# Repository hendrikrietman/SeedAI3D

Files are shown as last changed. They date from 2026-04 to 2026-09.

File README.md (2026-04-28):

# SeedAI3D

> AI-augmented, 3D-printable, breeder-first vacuum precision sowing element.

## What is this

A precision sowing element designed for plant breeders, not for industrial agriculture. Open-source, parametric, 3D-printable.

Commercial precision seeders (Monosem, MaterMacc, Stanhay) cost €5,000-25,000 and are built for thousand-hectare farming. They don't serve the plant breeding community well: small plots, frequent line changes, zero contamination tolerance, need for line-tracking.

SeedAI3D fills that gap. Estimated cost per element: €50-150 (printed parts + electronics + small parts).

## Distinguishing features

- **Vacuum pickup from seed-pool** — Earthway/MaterMacc-style
- **Zero-loss recovery bowl** surrounding disc seed-path — fallen seeds return to pool
- **Dual-tube self-cleaning** between lines (feeder + vacuum-cleaner-port)
- **Parametric design** adaptable to soybean, edamame, lima, snapbean
- **Optional RTK GPS integration** for plot-tracking and adaptive sowing speed

## Status

Prototype design phase. CAD architecture complete. First 3D-print pending.

This repository contains:
- Parametric OpenSCAD designs
- Three.js interactive viewer (real-time animated cycle visualization)
- Build documentation
- Design rationale and architecture decisions

## Architecture phases

- **Phase 1:** 132mm tilted disc with 60 teeth, 40 pickup-holes (Ø4mm)
- **Phase 2:** Bottom seed-pool architecture
- **Phase 3:** Singulator deflectors + guide funnel + 6-state seed lifecycle
- **Phase 4:** Vacuum chamber with O-ring sealing
- **Phase 6:** Integrated mal-plate (motor + drive + chamber in one)
- **Phase 7:** Transparent housing with integrated tubes (in progress)

## License

CC-BY-SA 4.0 — share-alike, attribution required.

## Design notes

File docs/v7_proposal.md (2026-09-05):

# SeedAI3D v7 — design proposal (unbuilt)

**Status:** proposal, September 2026. No parts printed. No SCAD yet; the geometry lives in the
parameter block of `viewer/v7/index.html` and is meant to be ported to `scad/` once the first
print of v5.8/v6.0 has answered the questions in §8.

Supersedes the v5.8.5 geometry in this repo. Carries over from v6.0 (June 2026, not pushed):
crop-swappable discs, the blow-off sector, the Ø20 vacuum nipple, 3 mm chamber back wall.

Interactive model: `viewer/v7/index.html` (seed physics, cut-away, explode, count mode).

## 1. Why revisit

v5.8 had 12 printed parts plus a lid ring, dust ring, O-ring cord, heat-set inserts and clip
posts. Most of them exist to fix problems the model itself introduced:

| v5.8 part | Why it existed | Why it goes |
|---|---|---|
| Geleider (catch chute), afstrijker 2, vertical drop tube | The viewer's free-fall model showed the seed missing the centre hole at θ=90° | On a 45° face, downhill at the top of the disc *is* radially inward. After vacuum cuts, a soybean rolls the 20 mm from the hole circle to the centre hole in ~0.1 s (a ≈ 4.5 m/s²). Tangential drift at 15 rpm is 4 mm. D9's "glide" already noticed this. |
| Lid ring, dust ring, 4 clip posts, M3 inserts | Cover the external teeth | Teeth move to an internal ring gear on the disc back; nothing on the front needs covering |
| Hopper, feeder tube, vac-cleanup tube | Seed supply and line change | Seeds rest on the 45° face; the pool is a collar around the bottom of the drum. Cleanout is by geometry (§4) or by the wall gate (field), not by a shop-vac 2000 times |
| NBR O-ring cord in a groove | Chamber seal | Static-seal geometry on a rotating face: line contact, high drag, wears the PETG disc. Replaced by a flat printed TPU gasket frame, as Monosem/MaterMacc do |

What was missing: a defined disc axis (v5 floats in a Ø134 recess), a seed sensor, a
singulator that can actually strip a double, chamfered holes, mounting bosses, a cover, and a
geometry that lets the *last* seed reach a hole.

## 2. Parts (nine)

1. **Disc** — Ø128 × 4, 32 holes Ø4 at R45 (pitch 8.8 mm; the v5 40 at R42 gave 6.6 mm, so
   adjacent soybeans touched), Ø50 centre hole, rim flange Ø133 × 2 on the front, internal ring
   gear (75 T, m1.5) on the back, 11.5 mm tall. Crop discs: swap hole count/diameter only.
2. **Plate** — Ø150 × 21. Back slab, ring-gear groove, full-360° seal land with the vacuum
   chamber (R41–49, θ 90–270) and blow-off pocket (θ 68–84) cut into it, outer wall, motor
   shaft bore, vacuum and blow-off nipples, dust drain slot under the ring cavity, two
   mounting bosses.
3. **Gasket** — TPU, two frames 2.5 mm wide, 1.5 mm thick, around chamber and blow-off.
4. **Funnel** — one lathe part: Ø54 front flange (retains the disc), Ø49.4 skirt (centre
   journal in the disc hole), cone Ø46→Ø24, bayonet flange behind the plate, exit tube.
5. **Pinion** — 25 T m1.5 on the NEMA17 shaft, sitting *behind* the seal land (z −16.5…−10.5)
   so no pickup hole ever passes over an open gear pocket.
6. **Collar** — static ring; flat underside 0.3 mm above the disc face (seals rim and
   flange), top face from R49 at the disc to R55 at the cover. See §4.
7. **Singulator finger** — hangs from the collar at θ≈232°, adjustable height.
8. **Cover** — clear PETG plate Ø144 × 3, three thumb screws.
9. **NEMA17 + TMC2208/2209** (bought).

Wall gate: the bottom 50° of the collar, hinged at its outer edge. Field mode only.

## 3. Z-stack (disc-local, front = +Z, mm)

| z | what |
|---|---|
| 20 … 23 | cover |
| −3 … 20 | collar rim / drum wall |
| −2.5 … −0.5 | disc rim flange (over the wall top: labyrinth) |
| −4.5 … −0.5 | disc body |
| −6 … −4.5 | TPU gasket |
| −10 … −6 | seal land, full 360°, R38–53 |
| −16 … −4.5 | ring gear on the disc back, R54.75 (tips) – 63 |
| −16.5 … −10.5 | pinion, centre (37.5, 0) |
| −21 … −16 | back slab |
| < −21 | motor, nipples, bosses |

Assembly: disc drops in from the front; funnel goes through the centre hole and locks with a
quarter turn behind the plate; cover on. Crop change is tool-free.

## 4. The last seed (collar geometry)

On a 45° disc the lowest point in the drum is the corner between the disc face and the wall.
With holes at R45 and a wall at R65 that corner is 14 mm (world) below the lowest hole. Every
seed ends there and no hole ever passes: v5–v7a could not empty by design.

Fix: make the hole circle the lowest point. The collar's top face runs from the hole circle
(R49, 0.3 mm above the face) to the cover (R55, z 20) at 73° to the disc face, i.e. 28° below
horizontal in the world. A surface must be steeper than 45° + friction angle relative to the
disc face for seeds to slide *inward*; 73° gives ~25° margin for soybean on PETG. Every point
in the drum then has a downhill path into the V between disc face and collar, whose bottom line
is the hole circle. Held seeds (R42–48) clear the collar edge by 1 mm.

Pool capacity in the V is small (tens of seeds); bulk lives in the hopper (§5).

## 5. Hopper

Vertical axis, 70° walls, transparent, one orifice, no ledges. A Ø25 tube (bore ≥ 3× seed
diameter; the v5 Ø14 would bridge with edamame) at ≥45° discharges onto the disc face *inside*
the hole circle at θ≈305°, so everything it delivers also drains into the V. Flow is
self-regulating: when the V is full the pile backs up to the orifice.

## 6. Modes and firmware

Same board and code for bench and planter. Board: Arduino Mega 2560 + RAMPS 1.4 (5 driver
sockets, 6 endstop inputs for IR gates, servo headers for gates, MOSFET outputs for blowers,
12864 LCD with encoder, buzzer and SD). 32-bit BTT SKR or ESP32/Arduino framework are
equivalent routes. Step rate at 20 rpm disc: 200 full steps/s per motor; 1/4 µstep, four
motors = 3200 steps/s, within a Mega + AccelStepper.

- **COUNT** (bench): target N from the encoder; full speed until N − (in-flight + 2), where
  in-flight = rpm·32/60·0.35 s is the number of seeds already released but not yet at the
  gate; then 2 rpm (one seed per second); stop on the Nth gate pulse; vacuum off so held seeds
  slide back. No bag on the holder → no count.
- **EMPTY** (last bag): 30 rpm, vacuum on, stop when the gate has been silent for 2.5 s
  (40 empty hole passes). Display the line total.
- **SOW** (planter): row list (line, N) from SD; live count vs N; row-done; gate cycle on
  the button: vacuum off → held seeds slide back → gate open ~1.5 s → close.
- IR gate in the funnel tube on an interrupt; occlusion time distinguishes a double.
- The SD CSV is the whole data path from winter counting to spring sowing: the bag counted on
  this disc is the row this disc meters.

## 7. Blower

40–70 mbar at the chamber for soybean-size seed: a small 12/24 V centrifugal blower per element
on a MOSFET output, not a shop vac.

## 8. Open questions — what the first print has to answer

1. Does the V actually feed the last seed? Collar edge radius and angle are the numbers to
   vary.
2. Gap-seal leakage with the TPU gasket vs. none.
3. Does a 75 T internal ring print true enough in PETG to mesh without backlash noise?
4. Doubles rate at the gate with the singulator at 2.4 mm above seed height.
5. Rim labyrinth: does anything reach the ring cavity, and does the drain clear it?
6. Not modelled: curved seed tube from the 45° exit to the furrow; row-unit bracket.

Counting accuracy is a hypothesis until a real disc has run a few thousand soybeans past a
real gate.

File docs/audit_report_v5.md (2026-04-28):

# V5 Audit Report — 2026-04-28 (post-Phase-5)

> Read-only inventory of `~/workspace/protisem-v4/`. No code or geometry was
> changed during this audit; only this report file was rewritten.
>
> This is the **second** audit of the V5 tree. The first (earlier today)
> drove the v5.6.0 Phase-5 commit and is preserved in this file's git
> history if needed for comparison. Everything below reflects the state at
> commit `5bafb4c` / tag `v5.6.0` / tag `phase5-backup`.

## Summary

The repository is in a **clean post-Phase-5 state**: 16 commits, working
tree clean, two new tags (`v5.6.0`, `phase5-backup`). Phases 1–5 are
implemented in code with matching SCAD + STL pairs; the entire validation
suite (36/36 checks) passes. **Phase 6 (gear drive + motor mount) has not
been started** — no parameters, no SCAD source, no STL, no viewer wiring.
That is expected; Hendrik asked for the backup tag *before* Phase 6.

The drift items the previous audit flagged have all been closed:
- Viewer `POOL` block now uses half-disc geometry (R_OUTER=55, depth 33,
  floor −50) consistent with `parameters.scad`.
- Stale `stl/v4_2/{disc,reservoir}.stl` removed from the tree.
- `decisions.md` gained D8 (V5 FLIP), D9 (vacuum-respecting glide),
  D10 (half-disc pool footprint).

The only remaining caveat: Phase-5 changes have **not been visually
verified in a browser** in this build environment (no display).

## File inventory

```
~/workspace/protisem-v4/

scad/
  lib/helpers.scad                  1.2 KB    2026-04-27 16:01
  lib/parameters.scad              15.0 KB    2026-04-28 15:43   ← Phase 5 added
  v4_1_disc.scad                    2.6 KB    2026-04-27 16:01
  v5_2_seed_pool.scad               8.8 KB    2026-04-27 21:31
  v5_3_barriere_geleider.scad       9.9 KB    2026-04-27 19:37
  v5_4_vacuum_chamber.scad          7.4 KB    2026-04-27 19:34
  v5_5_recovery_bowl.scad           6.9 KB    2026-04-28 15:44   ← NEW

stl/
  v4_1/disc.stl                     2.3 MB    2026-04-27 18:54
  v5_2/disc.stl                     2.3 MB    2026-04-27 18:55
  v5_2/seed_pool.stl              430.4 KB    2026-04-27 21:31
  v5_3/afstrijker.stl               2.4 KB    2026-04-27 19:38
  v5_3/afstrijker2.stl              2.3 KB    2026-04-27 19:38
  v5_3/geleider.stl                80.7 KB    2026-04-27 18:03
  v5_3/drop_tube.stl               82.4 KB    2026-04-27 18:01
  v5_4/vacuum_chamber.stl         150.0 KB    2026-04-27 19:35
  v5_5/recovery_bowl.stl           98.1 KB    2026-04-28 15:44   ← NEW
  (stl/v4_2/ deleted in v5.6.0)

viewer/
  index.html                        4.5 KB    2026-04-28 15:49
  viewer.js                        38.4 KB    2026-04-28 15:51   ← +clean cycle, POOL fix
  styles.css                        1.8 KB    2026-04-28 15:49   ← +.btn class
  package.json + package-lock.json + node_modules/three (vendored)
  vendor/three.module.js + vendor/addons/ (importmap targets)
  models/
    disc.stl                        2.3 MB    2026-04-27 18:59
    seed_pool.stl                 430.4 KB    2026-04-27 21:33
    afstrijker.stl + afstrijker2.stl
    geleider.stl
    drop_tube.stl
    vacuum_chamber.stl
    recovery_bowl.stl              98.1 KB    2026-04-28 15:47   ← NEW

validation/
  geometry_check.py                23.8 KB    2026-04-28 15:52   ← +check_recovery_bowl

docs/
  build_log.md                     38.4 KB    2026-04-28 15:54   ← +V5.6.0 entry
  decisions.md                     16.0 KB    2026-04-28 15:53   ← +D8/D9/D10
  audit_report_v5.md               17.6 KB    2026-04-28 15:35   ← rewritten by this audit

renders/
  v4_1/  4 PNG (Phase-1 disc)
  v4_2/  4 PNG (V4 era — still on disk; the SCAD source was retired)
  v5_2/  3 PNG (assembly + v5.5.1 + v5.5.2 iso)
  v5_4_anchor/  3 PNG (chamber anchor verification)
  v5_5/  v5_5_iso.png  183.7 KB  2026-04-28 15:47   ← NEW

scripts/
  render_all.sh                     1.6 KB
  update_viewer.sh                  0.5 KB
```

## Phase status

### Phase 1 — Disc
- SCAD: **present** (`scad/v4_1_disc.scad`)
- STL: **present** (`stl/v4_1/disc.stl`, copied to `viewer/models/`)
- `PICKUP_HOLE_DIA = 4.0 mm`  ✓ (per Phase-4 spec; soybean Ø~6 mm cannot pass)
- `PICKUP_HOLE_COUNT = 40`    ✓
- `DISC_TILT_DEG = 45°`       ✓
- Status: **complete, unchanged since first audit**

### Phase 2 — Reservoir / pool
- V4 top-funnel reservoir: **retired** (no SCAD source, no orphan STLs anymore)
- V5 bottom seed-pool: **active**, `scad/v5_2_seed_pool.scad`
  - Half-disc body, R_OUTER=55, footprint y ≤ 0
  - V-cone bottom 4×4 mm at (0, −30, floor+2), floor z=−50
  - Front-mount feeder tube (OD 18, ID 14, 60° elev) included
  - Top-mount vac-cleanup tube (OD 26, ID 22, 80° elev) included
- Status: **complete, unchanged since first audit**

### Phase 3 — Afstrijkers + geleider + animation
- Afstrijker 1 at θ=250° (singulator, height 8): **present** ✓
- Afstrijker 2 at θ=95° (release pusher, height 6): **present** ✓
- Geleider catch-mouth 40×20 at z=20, y_centre=30: **present** ✓
- Drop-tube OD 30 / ID 24, z_top=−6, z_bottom=−52: **present** ✓
- 6-state seed-lifecycle animation (pool → attached → falling → gliding →
  exiting → landed) with HUD counters: **implemented** ✓
- Status: **complete, unchanged since first audit**

### Phase 4 — Vacuum chamber
- Annular sector (R_in=30, R_out=50, depth 8, sector θ ∈ [90°, 270°]
  through 180°, world x ≤ 0): **present** ✓
- Ø 12 hose nipple, length 30 mm: **present** ✓
- Air gap 1.5 mm between disc and back-wall: implemented as
  `EPS = 0.01` slight inset at the disc-side opening (chamber's "front"
  is the disc back face); the seal is implicit at R=30 and R=50.
- **Boog-vormige rubber seal**: **not a separate modeled part**. The
  spec calls for a curved O-ring at R=30 and R=50; current SCAD leaves
  this as an implicit interface to be added in BOM/printing. Flagged
  but acceptable for digital geometry.
- Status: **structurally complete; seal element implicit (BOM concern)**

### Phase 5 — Recovery bowl + dual tubes + clean cycle
- Half-circle bowl around disc TOP half: **present** ✓ (NEW in v5.6.0,
  `scad/v5_5_recovery_bowl.scad`, `stl/v5_5/recovery_bowl.stl`).
  Half-disc shell, footprint y ≥ 0, R_OUTER=55, z ∈ [22, 50]. Floor
  flush on the geleider top with a 40×20 drain at y=30 aligned to the
  geleider catch-mouth. Disc-envelope subtraction (3 mm clearance)
  carves the slot where the rim crosses the outer wall.
- Feeder tube 60° from front: **present** ✓
- Vac-cleanup tube 80° from top: **present** ✓
- Self-cleaning animation button: **present** ✓ (NEW in v5.6.0).
  "Start clean cycle" button in the controls panel toggles
  `cleanCycleActive`. While active: vacuum forced to 0 internally,
  pool refill suppressed, pool seeds animated through the vac-cleanup
  tube at 3/s into a new "Cleaned" HUD counter.
- Status: **complete in code, awaiting browser eyeball verification**

### Phase 6 — Aandrijving + motor (gear drive + motor mount)
- BLDC motor mount: **MISSING**
- Drive pinion (20 teeth): **MISSING**
- Engagement with disc tooth-rim (60 teeth): **MISSING**
- Motor angle (45°): **N/A** (motor not yet placed)
- Motor rotation animation synchronous with disc: **N/A** (motor not yet present)
- No `parameters.scad` entries for `MOTOR_*` / `PINION_*`
- No `scad/v5_6_*.scad` source file
- No `stl/v5_6/` directory
- No viewer mesh load or toggle for motor / pinion
- Status: **not started — expected; Hendrik tagged `phase5-backup` first**

## Viewer state

`index.html` and `viewer.js` are loaded together via an importmap pointing
at `./vendor/three.module.js` and `./vendor/addons/`. Title now reads
"PROTISEM V5 — Phase 5 (recovery bowl + clean cycle)".

### STL meshes loaded (cache-busted with `?v=${Date.now()}`)
- `disc.stl`            — PETG-blue, rotates around `DISC_AXIS`
- `seed_pool.stl`       — translucent grey
- `afstrijker.stl` + `afstrijker2.stl` — dark grey
- `geleider.stl`        — translucent dark
- `drop_tube.stl`       — translucent dark
- `vacuum_chamber.stl`  — translucent dark blue
- `recovery_bowl.stl`   — translucent yellow-amber (NEW)

Procedural groups: pool-fill seeds (target 50, refill at <12), attached
seeds, falling/gliding/exiting/cleaning seeds (5 distinct materials),
pickup/release marker spheres, 40 per-hole vacuum-glow markers.

### UI toggles (controls panel, top-left)
1. RPM slider 0–30 (default 5.0)
2. Vacuum slider 0–100 (default 80)
3. Cross-section (cut +X half)
4. Pickup / release markers
5. Seed-pool fill
6. Seeds on disc (red)
7. Afstrijker 1 (pickup singulator)
8. Afstrijker 2 (release pusher)
9. Geleider (catch chute)
10. Drop-tube
11. Vacuum-kamer (transparant)
12. Vacuum-glow (active hole markers)
13. **Recovery bowl (top-half catch)** — NEW in v5.6.0
14. **"Start clean cycle" button** — NEW in v5.6.0

### State counters (info panel, top-right)
- Rotation angle
- Pool seeds
- On disc
- In geleider
- In drop-tube
- Sown (cum.)
- Skipped (cum.)
- Missed (cum.)
- **Cleaned (cum.)** — NEW in v5.6.0

### Animation
Implemented in `requestAnimationFrame` loop (`animate()`). Seed lifecycle:
pickup at θ=270° → travel on disc-front face → vacuum-respecting glide
to drop-tube at θ=90° → land. Singulator slip 5%, push-pusher 10%,
vacuum<5 → free-fall. Anchor verification logs PASS/FAIL on every STL
load. **fps not measurable in this audit environment** — the build
environment has no display; needs a browser run.

## Inconsistencies detected

### Carried-over from first audit — all resolved in v5.6.0

1. **Viewer `POOL` block stale**: closed. `viewer.js:97-105` now declares
   `{ rOuter: 55, wall: 2, depth: 33, zTop: -17, zFloor: -50, yCenter: -30,
   fillZ: -24 }`, matching `parameters.scad`. `placePoolSeed()` rewritten
   to spawn within the half-disc footprint with chord-bound x range.
2. **Stale V4 STLs**: closed. `stl/v4_2/{disc,reservoir}.stl` deleted via
   `git rm`; the (now-empty) directory is gone from the tree.
3. **`decisions.md` lag**: closed. D8 (FLIP), D9 (vacuum-respecting glide),
   D10 (half-disc pool) backfilled.

### Hardcoded values in viewer.js

The following geometric constants are hardcoded in `viewer.js`. All
values **match** `parameters.scad`. The viewer has no SCAD parser; this
is the intentional architecture (vendored constants kept in sync):
- `TILT = π/4`, `R_PICKUP = 42`, `N_HOLES = 40`, `SEED_RADIUS = 3`
- `PICKUP_THETA = 270°`, `RELEASE_THETA = 90°`
- `AFSTRIJKER_THETA = 250°`, `AFSTRIJKER2_THETA = 95°`
- `AFSTRIJKER_SLIP_PROB = 0.05`, `AFSTRIJKER2_PUSH_PROB = 0.10`
  (these are visualisation-only probabilities, not geometry; SCAD has
   matching values for documentation but nothing imports them)
- `GELEIDER`, `DROP_TUBE`, `POOL`, `BOWL` blocks ✓
- `DISC_THICKNESS = 4`, `AFS_HEIGHT = 8`, `AFS2_HEIGHT = 6` ✓
- `VAC_CLEAN_MOUTH = (0, -42, -43)`, `VAC_CLEAN_DIR` from 80° elev ✓
- `CLEAN_RATE = 3.0` (visualisation-only, no SCAD equivalent)

No drift detected.

### SCAD-vs-SCAD contradictions

None. Single canonical version of each component:
`v4_1_disc.scad` (Phase 1) → `v5_2_seed_pool.scad` (Phase 2 V5) →
`v5_3_barriere_geleider.scad` (Phase 3) → `v5_4_vacuum_chamber.scad`
(Phase 4) → `v5_5_recovery_bowl.scad` (Phase 5).
The retired V4 reservoir SCAD is not on disk (per D6).

### Phase 4 vacuum chamber

It works. Anchor verification (`viewer.js:472-484`) reports PASS for the
chamber STL centroid against the expected `(-26.67, +6.67, -6.67)`
post-FLIP position with `disc_plane_eq < 0` (back side). Earlier renders
are saved in `renders/v5_4_anchor/{front,iso,side_x}.png`.

### Seed position offset

The audit prompt says "5 mm offset langs FRONT_NORMAL". The code uses
`SEED_RADIUS = 3 mm` (`viewer.js:165`, `viewer.js:826`). Reasoning
(`viewer.js:124-126`): seed Ø=6 mm sits with its near pole tangent to
the disc-front face around the 4 mm hole, so seed-centre offset =
SEED_RADIUS = 3 mm. Geometrically correct; the prompt's "5 mm" appears
to be a misremember from an older revision. Same observation as the
first audit; **not changed**.

### Phase-5 specific notes

- Recovery bowl `disc_clearance` validation passes at min=2.92 mm vs
  nominal 3.00, with a 0.15 mm tolerance to absorb the OpenSCAD `$fn=64`
  chord error at R=66 (R·(1−cos(π/$fn)) ≈ 0.08 mm). Geometrically
  correct; the gap is faceting noise, not interference.
- Bowl floor at z=22 has an intentional slot in y∈[19.2, 24.8] where
  the disc body slab |z−y|≤2.83 passes through — same kind of slot the
  bottom pool has (D6) and the geleider has (D7). The slot leaks; real
  hardware will need rim-following sealing brushes, deferred.
- The bowl catches seeds in the y > 0 half-plane between roughly θ=90°
  and θ=120° release (where vacuum drop on the upper arc would deposit
  a seed). The y < 15 floor region is reachable but unlikely to receive
  seeds in normal operation.

### Air gap on vacuum chamber

The Phase-4 spec reads "1.5 mm air gap tussen disc en static back-wall".
The current SCAD uses `EPS = 0.01 mm` inset at the chamber-front /
disc-back interface. There is no explicit 1.5 mm gap modelled. Reading
of the original spec is ambiguous: the gap could be a mechanical
clearance for the rotating disc, or a design parameter for the seal.
Current model assumes the disc back face IS the chamber front cover
(zero gap, sealed by O-rings at R=30 and R=50). If Hendrik wants a
non-zero gap modelled, that would be a separate clarification before
Phase 6.

## Build log status

`docs/build_log.md` (655 → 715 lines) now covers:
- Phase 1 — Parametric disc + viewer bootstrap
- Phase 2 — Reservoir + viewer integration (V4 funnel, retired)
- Phase 2 fix — pickup/release θ correction
- Phase 2 V5 — architecture switch to vacuum bottom-pool (D6)
- Phase 3 V5 — afstrijker + geleider + lifecycle animation
- Phase 3 V5 visual fixes — seed offset, raised pool, release pusher
- Phase 3 V5 fix — `FRONT_NORMAL` derived from pool reference
- Phase 4 V5 — vacuum chamber + 4 mm holes + corrected seed mechanics
- V5 anchor-based verification
- V5 FLIP — seeds and chamber side-swap
- V5 polish — vacuum-respecting glide + front-face tube ports
- V5.5.0 — wider feeder + vac tube relocated to top
- V5.5.1 — V-cone in both X & Y, floor lowered
- V5.5.2 — half-disc footprint pool, wraps disc bottom 180°
- **V5.6.0 — Phase 5: top-half recovery bowl + clean-cycle animation** (NEW)

`docs/decisions.md` (132 → 248 lines) now contains 10 numbered decisions:
D1 (tilt axis), D2 (Phase-1 open items), D3 (three.js vendoring),
D4 (reservoir outlet — historical), D5 (θ=110/70 — superseded),
D6 (V5 architecture), D7 (geleider throat below disc-body slab),
**D8 (V5 FLIP)**, **D9 (vacuum-respecting glide)**, **D10 (half-disc pool)**.

What's not yet documented:
- Phase 6 architectural decisions (motor placement, gear ratio, mount
  attachment to housing). Will be written when Phase 6 starts.

## Git status

- Branch: `master`, working tree clean
- 16 commits since `Phase 0: scaffolding`
- Latest commit: `5bafb4c v5.6.0: Phase 5 — top-half recovery bowl +
  clean-cycle animation` (2026-04-28 15:56 UTC, today)
- Tags: `v4.1`, `v5.2`, `v5.3`, `v5.3.1`, `v5.4`, `v5.4.2`, `v5.4.3`,
  `v5.5.0`, `v5.5.1`, `v5.5.2`, **`v5.6.0`**, **`phase5-backup`** (last two NEW)
- `phase5-backup` is the explicit rollback point Hendrik requested before
  Phase 6 begins. `git reset --hard phase5-backup` restores the tree.

## What's complete

- Phases 1–5 all have SCAD source + STL output + viewer integration.
- All 36 validation checks PASS:
  - Phase 1 disc: 5 checks
  - Phase 2 V5 pool + clearance: 8 checks
  - Phase 3 afstrijkers + geleider + drop-tube: 12 checks
  - Phase 4 chamber: 4 checks
  - Phase 5 recovery bowl: 7 checks
- 6-state seed lifecycle animation runs with HUD counters
  (pool / on-disc / in-geleider / in-drop-tube / sown / skipped / missed
  / cleaned).
- Self-cleaning UI cycle implemented in viewer (button + state machine).
- Anchor-based verification gates every STL load with PASS/FAIL log.
- Backup tag `phase5-backup` exists; clean working tree.

## What's incomplete or broken

- **Phase 6 not started**: motor mount, drive pinion (20T), gear engagement
  geometry, motor rotation animation. None of: SCAD source, STL,
  parameters, viewer wiring. Expected per Hendrik's instruction.
- **Phase 5 browser eyeball not done**: recovery bowl visual, clean-cycle
  animation, and updated pool-seed spawn pattern all need a human at the
  viewer before Phase 6 starts. Build environment has no display.
- **Vacuum chamber rubber seal**: not a separate modeled part. Implicit
  at chamber-wall / disc-back-face contact line at R=30 and R=50.
  Acceptable for digital geometry, flag for BOM.
- **Air gap on chamber**: the original Phase-4 spec mentioned 1.5 mm
  air gap; current model uses 0.01 mm EPS inset (effectively zero).
  Re-confirm with Hendrik whether a 1.5 mm gap should be modelled.
- **Bowl/pool/geleider rim slots leak**: every component that the disc
  passes through has an envelope-subtraction slot. Real hardware needs
  rim-following sealing brushes (Monosem-style). Deferred consistently
  across D6, D7, and the new bowl. Not a Phase-5/6 blocker.
- **Recovery bowl floor in y < 15 region**: bowl floor is flat, so seeds
  bouncing into the y ∈ [0, 15] zone at z=22 just sit there until the
  next clean cycle. Acceptable trade-off; could be sloped toward the
  drain in a future revision if real-world testing shows accumulation.

## What needs fixing before Phase 6

1. **Browser eyeball pass** on the v5.6.0 viewer:
   - Open `http://localhost:8000/` (or whatever port `python3 -m
     http.server -d viewer` is running on).
   - Hard-reload (Ctrl/Cmd-Shift-R) to bypass the JS/HTML/CSS cache.
   - Confirm: recovery bowl renders as translucent yellow-amber on the
     disc top half; clean-cycle button drains the pool while the
     "Cleaned" counter ticks at ~3/s; pool seeds spawn within the
     half-disc footprint not the old rectangle; nothing visibly
     interferes with the disc rim.
2. **Decide on chamber air gap** (1.5 mm or 0). If non-zero, that's a
   small `parameters.scad` + `v5_4_vacuum_chamber.scad` change, ideally
   done before Phase 6 since the gear pinion will mechanically reference
   the same disc-back area.
3. **Phase 6 design questions to resolve before coding** — not blocking
   this audit, but worth lining up:
   - Motor placement: where does the BLDC sit relative to the disc rim?
     The disc tilts 45°, teeth are on the rim — pinion axis must be
     parallel to the disc plane, not vertical. Default: pinion engages
     at θ=0° (rim point world (66, 0, 0)) with pinion axis along Y'
     (the in-plane perpendicular).
   - Gear ratio: 20T pinion / 60T disc = 3:1 reduction (per CLAUDE.md).
     BLDC NEMA17 typical 3000–5000 rpm → disc 1000–1700 rpm before
     reduction; with 3:1 → disc 17–28 rpm. Matches the viewer's 0–30
     RPM slider range — no further reduction needed.
   - Mount attachment: housing wall at the +X side at z=0 — but the
     housing module isn't built yet. Phase 6 will need either a
     simplified standalone bracket or a placeholder housing wall.

## Recommended next steps

1. **Hendrik runs the browser eyeball pass**. Confirms 5a/5b work
   visually. If anything is off, ping me with what you see.
2. **Hendrik decides on the chamber air gap** (1.5 mm or keep at zero).
3. **Then start Phase 6** in this order:
   - 6a. Add `MOTOR_*` and `PINION_*` parameters to `parameters.scad`.
   - 6b. New `scad/v5_6_gear_drive.scad` — pinion + simple motor body
     box + minimal mount bracket.
   - 6c. STL exports to `stl/v5_6/`, viewer mesh loads.
   - 6d. Wire pinion rotation in viewer animation: `pinion.rotation =
     -disc_rotation × 60/20 = -3·rotationAngle` around the in-plane
     perpendicular.
   - 6e. Validation: `check_pinion()` for tooth count, OD, axis
     alignment. Anchor-verify the pinion centroid sits on the rim
     engagement point.
   - 6f. Commit `v5.7.0`, optionally tag a `phase6-backup` for the
     same reason this `phase5-backup` exists.
4. **Open project decisions** still unresolved from `CLAUDE.md`:
   - Phase 7 bearing choice (edge rollers default per D2.1).
   - Print material PETG (fixed per D2.3).
   - First physical print after Phase 3 was the original recommendation
     — re-confirm now that Phase 5 is in.
   None block Phase 6 start.

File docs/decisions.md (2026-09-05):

# Architectural Decisions

## D1 — Disc tilt axis: world-X, not world-Y (Phase 1)

**Date:** 2026-04-27.
**Question:** The plan stated *disc-normal = (sin45°, 0, cos45°)* AND *pickup-zone = (0, 29.7, 29.7)*. These are inconsistent — they describe two different rotation axes.

**Decision:** Honour the pickup-zone coordinate. Tilt the disc with `rotate([45, 0, 0])` (around world X). Disc-normal becomes `(0, -sin45°, cos45°)`.

**Why:** The pickup-zone coordinate is more specific, more useful for downstream geometry (reservoir outlet must drop seeds onto it), and easier to test. The disc-normal phrasing in the spec was a typo (X/Y swap).

**Consequence:** All later phases must follow this convention. The reservoir outlet sits above `(0, 29.7, 29.7)`. The release zone is at `(0, -29.7, -29.7)`.

---

## D2 — Phase-1 open decisions resolved (2026-04-27)

1. **Phase-7 bearing:** edge rollers (default).
2. **Viewer deployment:** local only. `python3 -m http.server -d viewer 8000`.
3. **Print material:** PETG (transparent, sterk, hittebestand).
4. **First physical print:** later than Phase 3.
5. **Working language:** English.

---

## D4 — Reservoir outlet clearance: 17 mm above pickup-top, not 5–8 mm (Phase 2)

**Date:** 2026-04-27.
**Question:** The plan called for the reservoir outlet to sit 5–8 mm above the pickup-zone, with a Ø12 outlet and ≥5 mm clearance from the disc everywhere.

**Geometric finding:** With the disc tilted 45° around X, the disc top surface follows the plane `z = y + 2.828`. A horizontal Ø12 outlet centered above the pickup-top point `(0, 28.28, 31.11)` has its outer wall (Ø16 with 2 mm wall) reaching to `(0, 36.28, z_out)`. For ≥5 mm perpendicular clearance to the disc top plane:

> `cos(45°) · (z_out − 36.28 − 2.828) ≥ 5  ⇒  z_out ≥ 48.1`

i.e. **the outlet must be ≥17 mm above the pickup-top point**. With 5–8 mm clearance, the outer rim clips the rising disc surface.

**Decision:** Set `RESERVOIR_OUTLET_CLEARANCE = 17` mm. Outlet at `(0, 28.284, 48.113)`. Drop distance to disc-top is 17 mm. Validation confirms ≥6.5 mm minimum clearance (`reservoir_disc_clearance` check).

**Consequence / future options:** to recover the original 5–8 mm range, either (a) shrink the outlet (Ø6–8), (b) tilt the outlet plane parallel to the disc (seeds would no longer fall vertically), or (c) shape the outlet asymmetrically — bias the +Y rim inward. Defer until physical testing shows whether 17 mm drop causes seed bouncing.

---

## D6 — V5 architecture: vacuum pickup from bottom seed-pool (Phase 2 rewrite)

**Date:** 2026-04-27.
**Question:** D5 placed pickup and release symmetrically near the disc top (V4-drawing interpretation). Hendrik then directed a complete architecture switch: V4 (gravity-fed top reservoir) → V5 (vacuum pickup from a bottom seed-pool, Monosem/MaterMacc/vSet pattern).

**Decision:** Adopt V5. Concretely:

- Pickup at **θ=270°** (disc bottom): world (0, -29.7, -29.7). Disc dips into an open seed pool.
- Release at **θ=90°** (disc top): world (0, +29.7, +29.7), directly above the central drop hole.
- Seed travels **180° along the disc rim** with θ decreasing (Option 1 — front face rises into the release zone).
- Reservoir is no longer a top funnel. It is a **60 × 40 × 20 mm open bowl** centred at (0, -30, -35), with a V-trough bottom (6 mm strip) so seeds gather along the disc-rim dip line.
- Vacuum behind the disc draws seeds against the disc FRONT face (the face whose normal has +Y component).

**Why V5 over V4:**
- **Singulation precision.** Vacuum self-limits to one seed per hole (extra seeds fall back into the pool). Gravity-fed top reservoirs over-feed and need an `afstrijker` to scrape excess.
- **Zero kinetic energy at pickup.** Seeds in a pool are stationary; vacuum captures them at v=0. Top-reservoir seeds arrive at the disc with several mm/s of velocity from the drop, increasing bounce risk.
- **Natural reservoir emptying.** Vacuum draws from the lowest point — pool empties uniformly.
- **Lower CG.** Reservoir mass is now low in the housing.
- This matches the dominant precision-seeder pattern (Monosem MS, MaterMacc MS-300, Precision Planting vSet, John Deere ExactEmerge).

**Geometric consequences (open issues, see build_log):**

1. *Disc TEETH dip below pool floor.* Tooth tips at α=270° sit at world z=-48.09; pool floor at z=-45 → 3 mm interference. SCAD model digitally seals the floor by clipping the envelope subtraction; physical hardware would need either a lower floor (z=-50) or no teeth at this stage. Validation reports `disc_above_floor: gap=-2.22 mm` until Hendrik picks one.
2. *Side-wall slots leak.* The disc passes through slots in X=±30 walls. Real Monosem-style sealing brushes are deferred to Phase 3+.
3. *Released-seed miss confirmed.* At release, tangential velocity is +22 mm/s in +X (5 RPM); free-falling seed lands on the disc back face. Phase 3 deflector is mandatory.

**Consequence for prior decisions:**
- D4 (outlet clearance trade-off) is now historical — there is no outlet.
- D5 (pickup θ=110°, release θ=70°) is superseded by this decision.

**Files retired:** `scad/v4_2_reservoir.scad` (deleted from tree, kept in git history).
**Files added:** `scad/v5_2_seed_pool.scad`, `stl/v5_2/{disc,seed_pool}.stl`, `renders/v5_2/`.

---

## D5 — Pickup at θ=110°, release at θ=70° (Phase 2 fix)

> *Superseded by D6.* The θ=110°/70° interpretation honoured a possible reading of the V4 drawing but was wrong about the architecture entirely (top reservoir vs bottom pool). Kept here for traceability.

**Date:** 2026-04-27.
**Question:** The original Phase-2 build placed the release at the disc's LOWEST point (0, −29.7, −29.7) — the geometric "180° opposite" of the pickup. The V4 concept drawing's "Vooraanzicht schijf" panel shows pickup AND release both near the TOP of the disc, symmetric around the Y axis. Seeds travel the LONG way around the rim (~320°), not the short way through the bottom.

**Decision:** Pickup at θ=110°, release at θ=70° on the pickup-hole circle (R=42), where θ is the disc-local angle and world coords come from `(R·cosθ, R·sinθ·cos45°, R·sinθ·sin45°)`. Both markers at world Z = 27.907 mm, X-separated by 28.73 mm. Seed path is CCW: 110° → 200° → 290° → 360° → 70° = 320° of rotation.

**Reservoir outlet** now shifts to `(−14.365, 27.907, 35.000)` — directly above the new pickup. Vertical clearance dropped from 17 mm to 7.1 mm.

**Geometric consequence — clearance regression:** with the outlet centered at y=27.907 and the Ø16 outer wall reaching to y=35.907, the disc-top plane z = y + 2.828 sits at z=38.735 at that rim. The outlet bottom is at z=35, so the +Y outer rim is BELOW the disc top by 3.7 mm vertical (≈2.6 mm perpendicular). Validation confirms: `min clearance = 0.10 mm` at (−19.7, 32.3, 35.0). The outlet wall and the disc body interfere.

To restore ≥5 mm perpendicular clearance with the outlet centered above PICKUP_POS, the +Y outer rim point must satisfy `z − y ≥ 9.9`. Three options:

1. **Raise outlet to z ≈ 45.8 mm** (clearance back to ~17.9 mm above pickup). Geometrically clean, but the seed drop-distance grows again — risk of bouncing.
2. **Shrink outlet to Ø6 inner / no outer flange, wall=1**: +Y rim at y = 27.907 + 4 = 31.907 → z − y = 35 − 31.907 = 3.1, still below the 9.9 threshold. So shrinking alone doesn't fix it; would need to also raise z slightly.
3. **Tilt the outlet plane parallel to the disc** (rotate outlet ≈45° around X so the bottom rim follows the disc surface). Seeds drop along the disc normal, not vertically — physics still works because the disc surface is the relevant plane.
4. **Asymmetric outlet** — bias the +Y rim inward (D-shaped or oval bottom). Cleanest visually, but harder to print.

**Pending Hendrik's call.** Until then, the build keeps the user's specified marker/outlet positions and the validation script reports the clearance violation honestly rather than masking it.

**Drawing-derived insight:** Front face of the disc rotates UP at the release side (Hendrik's "Schijf draait aan voorzijde omhoog"). With +ω around `DISC_AXIS = (0, −sin45°, cos45°)`, the velocity at release (+14.4, 27.9, 27.9) is in the (0, +y, +z) direction → front face rises into the release zone. Current viewer rotation direction is correct; no reversal needed.

---

## D7 — Geleider throat below disc-body slab; slot subtraction for clean rotation (Phase 3)

**Date:** 2026-04-27.
**Question:** Spec put the geleider throat at world (0, 0, 5) and catch-mouth opening at z=20. A straight lofted hull from a 44×24 mm rectangular mouth at z=22, y=30 to a Ø34 circular ring at z=6, y=0 unavoidably passes through the disc-body slab `|z − y| ≤ 2.83 mm` at intermediate z. The disc top face at θ=90° sits at z = y + 2.83; the loft's centerline at z=15 sits at y≈16, where disc body is present at |x|≥13, and the loft has X-extent ±20. Result: 249/5000 sampled geleider surface points landed within 1 mm of disc — direct interference.

**Decision:**
1. **Lower the throat to z = −6** (was 5). With y=0 at the throat, |z−y|=6 > 2.83 → the throat sits cleanly below the disc-body slab. The path centerline now satisfies `0.9·y − 6 < y − 2.83` ⇔ `y > −31.7` — true everywhere on the path.
2. **Subtract the disc envelope (with 3 mm clearance) from the geleider** — same trick used on the seed-pool side walls. Carves a slot through the geleider where the disc passes; rotation is unobstructed; clearance ≥3 mm validated by trimesh proximity sampling.
3. **Drop-tube top moves with throat** — DROP_TUBE_Z_TOP = −6.

**Why not narrower mouth or higher mouth instead:**
- Narrower mouth (X-shrink): the mouth catches a +X-velocity seed at release. With 5 RPM tangential speed 22 mm/s and ~0.04 s fall time, the seed displaces ~1 mm in +X — Ø10 mouth is enough kinematically. But disc body width across the loft is ~|x| ∈ [13, 60], and even a narrow mouth's *loft surface* (sides flaring from throat to mouth) crosses the disc body unless the throat is below the body slab.
- Higher mouth: would put the mouth opening at z > 27 to clear the disc body at y=30 (where body face sits at z=27.17). Seed drop distance and bounce risk grow.

**Consequence:**
- Slot subtraction means the geleider leaks seeds where the disc passes through. Real hardware needs Monosem-style sealing brushes around the disc rim — same as the seed-pool side-wall slots from D6. Deferred to a later phase, flagged as a design constraint.
- Drop-tube starts higher up (z=−6 instead of z=5), making it 11 mm longer than the spec assumed. Still fits comfortably through the disc Ø50 central hole (10 mm radial slop).

**Files changed:** `scad/lib/parameters.scad` (GELEIDER_THROAT_Z, DROP_TUBE_Z_TOP), `scad/v5_3_barriere_geleider.scad` (added `disc_envelope_for_geleider()` subtraction), `validation/geometry_check.py`.

---

## D8 — V5 FLIP: seed-attachment side swapped to operator-visible (post-Phase-4)

**Date:** 2026-04-27.
**Question:** Phase 4 closed with the vacuum chamber on the operator-visible
side of the disc and seeds attaching on the operator-far side. Hendrik
inverted this: chamber must hide *behind* the disc, seeds and afstrijkers
must sit on the *visible* face.

**Decision:** Post-flip frame — `FRONT_NORMAL = (0, −sin45°, +cos45°)`,
i.e. seeds attach in the `disc_plane_eq > 0` half-space (camera at
+X, −Y, +Z is in eq>0). Chamber centroid post-flip is `(−26.67, +6.67,
−6.67)`, eq = −9.43 (opposite side, hidden).

**Why:** Operator must see the seeds and the singulator blades during
calibration; the rotating-seal interface against the disc back face is
internal and doesn't need to be visible. Same orientation as physical
Monosem/MaterMacc machines.

**Implementation:** SCAD-side `mirror([0,0,1])` added to `vacuum_chamber()`
before the tilt rotation; both afstrijker SCAD modules had their pre-tilt
mirror *removed* so they stay on the seed-attachment face. Anchor-based
verification in `viewer.js` (centroid-vs-expected with 1.5–2.0 mm tol)
gates every STL load and prints PASS/FAIL to console.

**Files changed:** `scad/v5_3_barriere_geleider.scad`,
`scad/v5_4_vacuum_chamber.scad`, `viewer/viewer.js` (anchor block).

---

## D9 — Vacuum-respecting release glide instead of free-fall + geleider catch

**Date:** 2026-04-27.
**Question:** At natural release (θ=90°) the seed has tangential velocity
~22 mm/s in +X (5 RPM). A free-fall trajectory with gravity passes through
the disc-body slab `|z−y| ≤ 2.83 mm` on its way down to the geleider
catch-mouth — the seed visibly clips through the rotating disc.

**Decision:** Two-stage glide replaces free-fall when vacuum is on:
- **Stage 1** (0.45 s): seed slides along the disc-front face from rim
  point at θ=90° inward to a midpoint above the central axis (R=0,
  Z=+3 in disc-local), staying 3 mm above the disc face throughout.
- **Stage 2** (0.30 s): vertical drop through the central Ø50 hole into
  the geleider throat at z=−5.

The original free-fall + geleider-catch path is preserved as a fallback
for vacuum-loss mid-cycle (the "missed" counter still increments when
free-falling seeds escape the catch-mouth).

**Why:** Physically realistic — vacuum still holds the seed against the
disc as it crosses θ=90°; gravity wins only after the seed clears the
rim. The two-phase trajectory respects this without simulating full
fluid dynamics. Visually no clipping through the disc.

**Files changed:** `viewer/viewer.js` (`glideToThroat()`,
`updateGliding()` two-stage branch).

---

## D10 — Half-disc bottom pool footprint (v5.5.0–v5.5.2)

**Date:** 2026-04-27.
**Question:** Original V5 pool was a 60 × 40 × 20 mm rectangular box at
floor z=−45. Several issues stacked up: tooth tips at θ=270° dipped
3 mm below floor (D6); side walls were vertical 4-mm slits where the
disc passed through (leak risk); fixed front/back orientation didn't
catch seeds detaching mid-arc.

**Decision (three iterations):**
1. **v5.5.0** — relocated vac-cleanup tube from front-mount (45° elev)
   to top-mount (80° elev = 10° off vertical), widened feeder bore from
   OD16/ID12 to OD18/ID14 (reduces soybean bridging risk).
2. **v5.5.1** — V-cone bottom in both X and Y (4 × 4 mm floor patch),
   floor lowered from −37 to −50 mm. Resolves the long-standing
   `disc_above_floor` validation failure: with floor at −50 the disc
   teeth (lowest at z ≈ −48.1) no longer reach the floor at all.
3. **v5.5.2** — rectangular footprint replaced with a half-disc body
   (R_OUTER=55, opening at y=0, footprint y ≤ 0). Wraps the disc
   bottom 180° in plan view → catches seeds detaching anywhere in
   the bottom-arc XY-projection.

**Trade-off accepted:** half-disc + single-point V-cone gives 28° side-
slope (toward ±X), below the ≥35° self-feeding spec. Soybean rest angle
is ~25–30°, so it works but is tight; mitigations deferred (curved
trough following disc rim, rim-following internal rib, or tighter
R_OUTER ≈ 40 for ~38° slopes at the cost of catch area).

**Why this footprint:** R_OUTER=55 was sized to keep the existing tube
anchors INSIDE the half-disc body (feeder anchor radius 52.2, vac
anchor radius 42, both < 55). Phase-5 recovery bowl mirrors this
R_OUTER on the y ≥ 0 side for visual symmetry.

**Files changed:** `scad/lib/parameters.scad` (SEED_POOL_R_OUTER,
floor=−50, depth=33, feeder/vac tube params),
`scad/v5_2_seed_pool.scad` (half-cylinder body, V-cone hull cavity,
vac tube tilted 80° top-mount), `validation/geometry_check.py`
(`y_back_edge` replaces `y_back_face`).

---

## D11 — Integrated disc-mal element (Phase 6)

**Date:** 2026-04-28.
**Question:** Phase 4 (vacuum chamber) and Phase 5 (recovery bowl, feeder
+ vac-cleanup tubes, clean cycle) shipped as separate components, each
with its own SCAD source and its own attachment to the housing. Hendrik
re-scoped Phase 6 to consolidate everything disc-related into ONE
3D-printable element ("mal-plate"): a flat plate that holds the disc
(via a circular recess), drives it (NEMA17 stepper + 20T pinion engaging
the disc tooth-rim), and provides vacuum suction (180° arc-sector
cavity inside the plate, sealed against the disc-back face by an O-ring
in a groove on the recess-back-wall).

**Decision:** Adopt the integrated mal-plate. Concretely:

- Plate body 180 × 180 × 15 mm in plate-local frame; tilted 45° around
  world-X to match the disc.
- Disc-recess: cylindrical pocket Ø 134 × 5 mm deep on the plate-front
  face. Disc floats in the recess with 0.5 mm front and back clearance.
- Vacuum chamber: cavity inside the plate, 180° sector covering θ ∈
  [90°, 270°] through 180° (world x_local ≤ 0). Radii moved 2 mm outward
  from Phase 4 (R = 32..52, was 30..50) so the R=42 pickup circle sits
  centred (10 mm margin each side instead of 12/8).
- O-ring groove on the recess-back-wall (the chamber-front-wall in the
  chamber sector): ISO-3601 face-seal style for 2.5 mm NBR cord, 3.2 mm
  wide × 1.9 mm deep. Path follows the chamber perimeter (outer arc R=53,
  inner arc R=31, two end straights). Cord protrudes 0.5 mm compressed —
  this IS the air gap between disc-back and chamber-front-wall.
- Motor cut-out at θ=180°: 36 × 36 mm rectangular opening through the
  plate. Drive pinion 20T m=1.5 (OD ≈ 33) at world (-75, 0, 0).
- Hose nipple Ø 12 OD × 30 mm long, sticks out plate-back at chamber
  midpoint (-42, 0, plate-back).

**Why over keeping components separate:**
- Single printable part replaces 2-3 separate prints + an assembly step.
- The chamber-disc seal is geometrically tied to the recess (via the
  O-ring groove path), so the plate is the natural place for it.
- Matches commercial precision-seeder design (Monosem, MaterMacc, vSet)
  where the disc rotates inside an integrated frame.
- All other components (bowl, geleider, drop-tube, pool) attach to the
  plate via M3/M5 inserts, not to the housing — single structural
  reference.

**Why over the standalone Phase-4 chamber:**
- The standalone chamber needed a back wall (modeled), a seal interface
  (implicit), and four bolts to attach to a hypothetical housing. The
  mal-plate IS that housing wall, with the chamber as a cavity inside it.
- The 1 mm air gap from v5.6.1 (translate-based) is replaced by the
  O-ring's 0.5 mm compressed protrusion — geometrically determined by
  the seal, not a free parameter.

**Files retired:** `scad/v5_4_vacuum_chamber.scad` and
`scad/v5_5_recovery_bowl.scad` moved to `scad/archive/`. Their STLs
deleted from `stl/` and `viewer/models/`. The Phase-5 work (bowl,
clean-cycle UI) will be rebuilt on top of the mal-plate (per Hendrik's
"option (c) discard Phase 5"); the clean-cycle button stays in the
viewer for now since it's UI-only.

**Files added:** `scad/v5_6_disc_mal.scad`, `stl/v5_6/mal_plate.stl`,
`stl/v5_6/pinion.stl`, `stl/v5_6/motor.stl`.

**Geometric trade-offs noted but not blocking:**
- Disc teeth are trapezoidal (not involute) at effective module ~2.
  Pinion is also trapezoidal, but specified at module 1.5. Mesh isn't
  geometrically perfect but visually plausible — this is a visualisation
  model, not a CFD/FEA target.
- Pinion centre at X=-75 puts pinion teeth tips at X=-58.5, 1.5 mm past
  the disc OD-without-teeth (R=60). They mesh with the disc tooth-rim
  band in this region. Physical hardware will need a real involute
  pinion sized to match the actual disc tooth pitch.

---

## D12 — Disc retention without external bearings (Phase 6)

**Date:** 2026-04-28.
**Question:** CLAUDE.md D2.1 set Phase 7 = "edge rollers (3× 608ZZ)"
as default for disc support. Phase 6 mal-plate makes that scheme
unnecessary by floating the disc in the recess.

**Decision:** Disc is held by:
- Front: lip on plate-front-face (the recess opening, Ø < disc OD by
  the front clearance). Prevents the disc falling forward.
- Back: O-ring in groove on recess-back-wall. The cord pressure
  + the static plate-back-wall behind the chamber prevents the disc
  falling backward. (Compressed cord seats firmly against disc-back.)
- Radial: 1 mm clearance between disc OD-with-teeth (132) and recess
  ID (134). Disc rotates freely on a film of dust/lubricant. Real
  hardware will need either a low-friction insert (PTFE ring at the
  recess wall) or a small radial bearing race — TBD when first prints
  show wear behaviour.

**Why over edge rollers:**
- Three external 608ZZ rollers add complexity, cost, and assembly time.
- The disc is large (Ø 132, 4 mm thick) and light — radial loads from
  vacuum + gear mesh are small compared to roller-bearing capacity.
- Mal-plate recess approach matches commercial seeders (Monosem MS,
  MaterMacc MS-300) which do not use edge rollers either.
- One fewer phase to build (Phase 7 retired).

**Consequence:** Phase 7 (edge-roller bearings) is **retired**.
CLAUDE.md plan and `docs/decisions.md` D2.1 superseded.

**Open**: When the first physical print shows whether the recess +
O-ring + disc weight is enough to keep the disc rotating without slop,
we'll know if a radial PTFE insert is needed. Hendrik flagged this is
something to revisit when Phase 7 would have been built.

---

## D13 — Phase 7 transparent housing; mal-plate disc-recess overlap accepted

**Date:** 2026-04-28.
**Question:** Phase 7 introduces a hopper that the disc-rim must dip into
at θ=270°. The mal-plate (Phase 6) has a Ø 134 disc-recess that fully
encloses the disc rim at every θ. Cutout in mal-plate would let disc-rim
access the hopper but violates the spec's "DO NOT TOUCH mal-plate" rule.

**Decision:** Accept the visual overlap between hopper and mal-plate at
θ=270° in the viewer. Both meshes render independently; the disc-rim
visually dips into the hopper through the mal-plate volume. This is
inconsistent for physical hardware but acceptable for the visualisation
model.

**Why not a surgical cutout:** Hendrik's "DO NOT TOUCH mal-plate" rule
is more important than geometric realism for this iteration. A future
phase can punch the cutout when ordering / printing the real plate.

**Why not "discard the mal-plate":** the mal-plate carries the chamber,
the O-ring groove, the motor mount, and the gear cutout. Removing it
would unwind a lot of Phase 6 work for marginal visual gain.

**Consequence:** Same kind of "leak" as the existing seed-pool / geleider
slot subtractions (D6, D7) — the digital model doesn't enforce volume
exclusivity. Real hardware will need a properly cut access window.

**Files affected:** None. The overlap is pure visualisation.

---

## D3 — Three.js vendoring strategy (Phase 1)

**Decision:** Vendor only the three files we use (`three.module.js`, `OrbitControls.js`, `STLLoader.js`) into `viewer/vendor/`, total 1.3 MB. Resolve via importmap.

**Why:** Hendrik wants fully local serving. `npm install` of the full package pulls in 32 MB of unused source/examples. Vendoring three files keeps the repo small and makes `python3 -m http.server -d viewer` work without any other tooling.

**Consequence:** When updating three.js, copy the same three files from `node_modules/three` (regenerated via `npm install three` in `viewer/`).
Append to docs/decisions.md

## v7 (2026-09) — proposal, SCAD released, unbuilt

- **D19** Remove geleider, afstrijker 2 and the vertical drop tube. On the 45° face, downhill at θ=90° is radially inward; the released seed rolls into the centre hole by itself.
- **D20** Drive by internal ring gear on the disc back (75 T m1.5 involute) with a 25 T pinion on the NEMA17, both behind a full-360° seal land. External teeth, lid ring, dust ring, clip posts and inserts are removed.
- **D21** The funnel is the centre bearing (Ø49.4 skirt in the Ø50 hole), the disc retention (Ø54 front flange) and the drop chute; bayonet lugs behind the plate. Disc swap is tool-free.
- **D22** 32 holes at R45 (8.8 mm pitch) for soybean. 40 at R42 put adjacent seeds in contact.
- **D23** Chamber seal is a flat printed TPU gasket frame (2.5 × 2.2 mm in a 0.5 mm recess), not an O-ring cord. First print runs a leak test with and without it.
- **D24** Closed drum: clear cover, disc rim flange over the wall top with the collar outside it (labyrinth), drain slot under the ring cavity.
- **D25** Collar: static ring whose top face climbs at 73° from the hole circle to the cover. Makes the hole circle the lowest point in the drum so the last seed always reaches a hole. Replaces the trough lip.
- **D26** Hopper orifice discharges onto the disc face inside the hole circle, via a Ø25 tube at ≥45°; hopper is vertical, 70° walls, one orifice, transparent.
- **D27** Count mode: speed-dependent slow-down point (N − in-flight − 2), 2 rpm finish, stop on the Nth gate pulse. Empty mode: 30 rpm until 2.5 s of gate silence.
- **D28** Line change: bench empties through the disc into the last bag (every seed counted); planter empties through a collar gate into a bin. Purge port and vac-cleanup tube removed.
- **D29** Vacuum enters through an 8 × 30 mm slot in the chamber floor and a flange-mounted barb with a TPU flat gasket; no counterbore in the island (a Ø20 counterbore broke into the ring groove in the first SCAD pass).
- **D30** Sensor in a separate black elbow: Ø14 throat, two crossed modulated IR pairs, pulse-width doubles detection. Index magnet in the disc, hall sensor in the plate: per-hole expectation windows.
- **D31** Controller: FYSETC E4 (ESP32, 4 × TMC2209, BLE/Wi-Fi). The console is the viewer page over Web Bluetooth or a Raspberry Pi kiosk; no LCD. Board tray fits Mega+RAMPS and Pi as alternatives.
- **D32** Vacuum setpoint 25–30 mbar to start, pressure tap to a sensor, bleed valve; tune on the doubles count, not upward by habit.
- **D33** Hopper tube mouth is flush with the collar face at R53, not 5 mm above the disc inside the hole circle: a seed arriving at ~1 m/s on the 45° face bounces up to 70 mm toward the funnel; sliding down the collar into the V it cannot. Self-regulation then happens at the V.

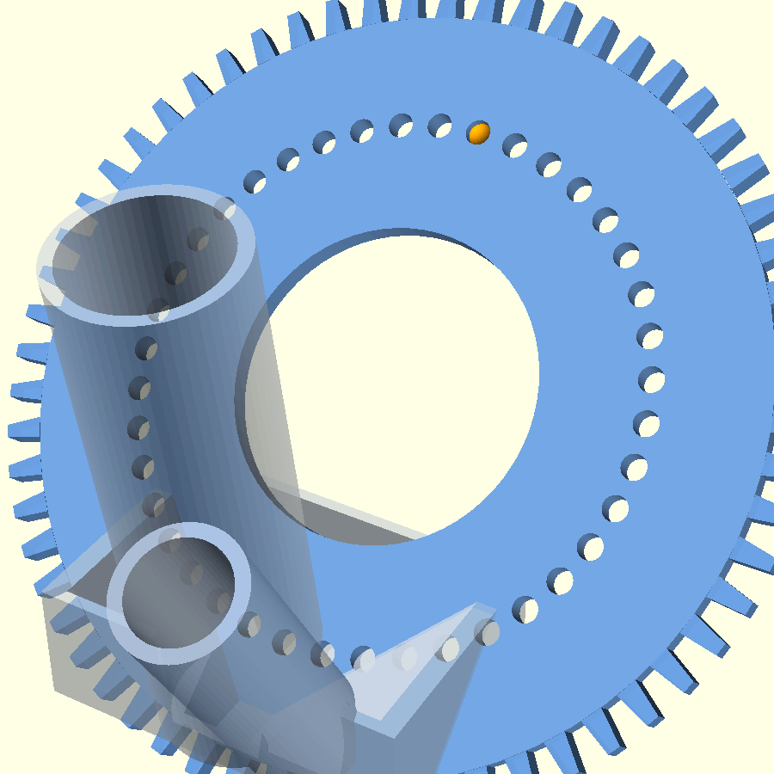
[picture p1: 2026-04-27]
renders/v5_4_anchor/iso.png

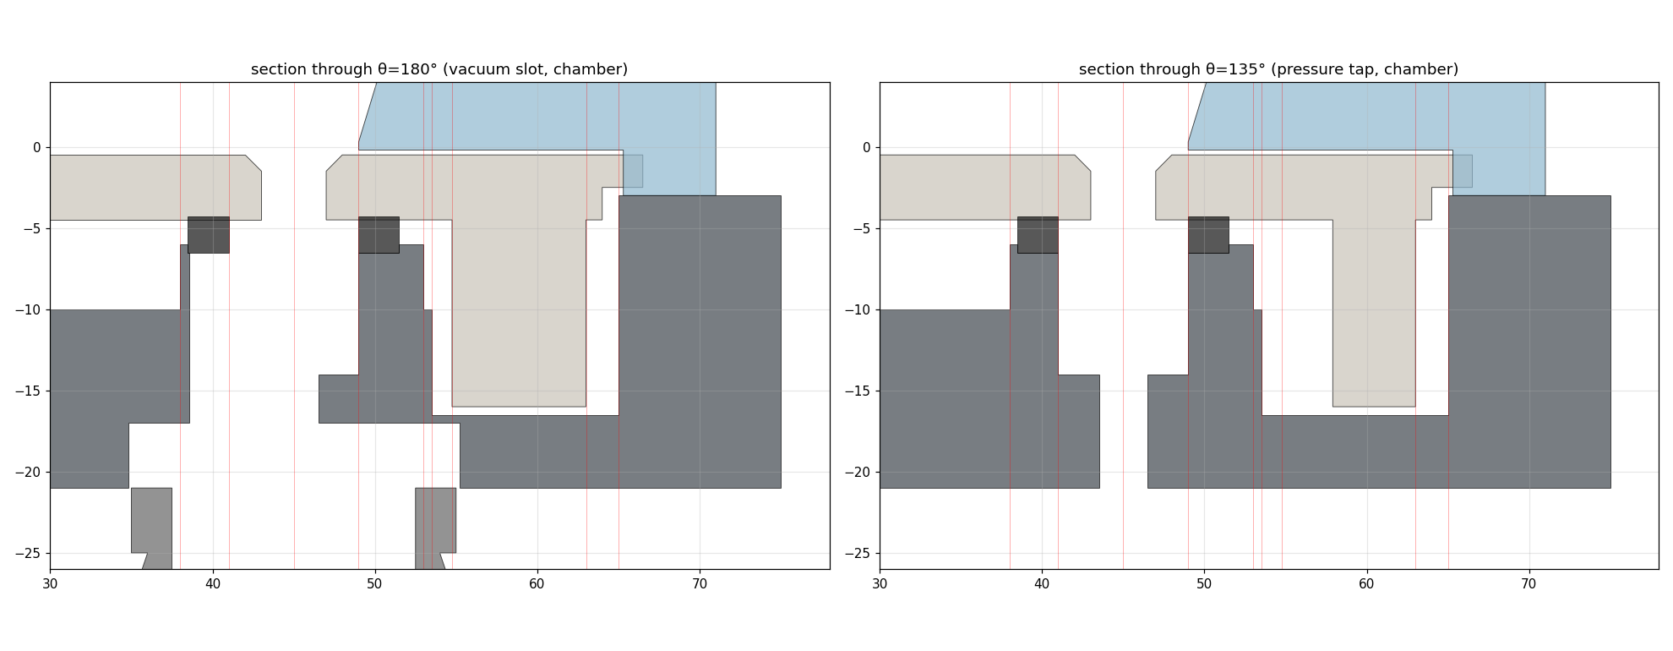
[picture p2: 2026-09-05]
docs/v7_sections_chamber.png

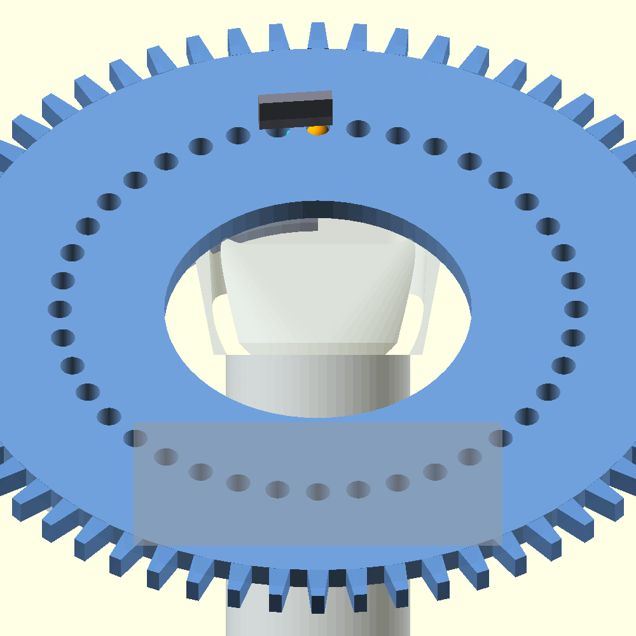
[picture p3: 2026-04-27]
renders/v5_4_anchor/front.png

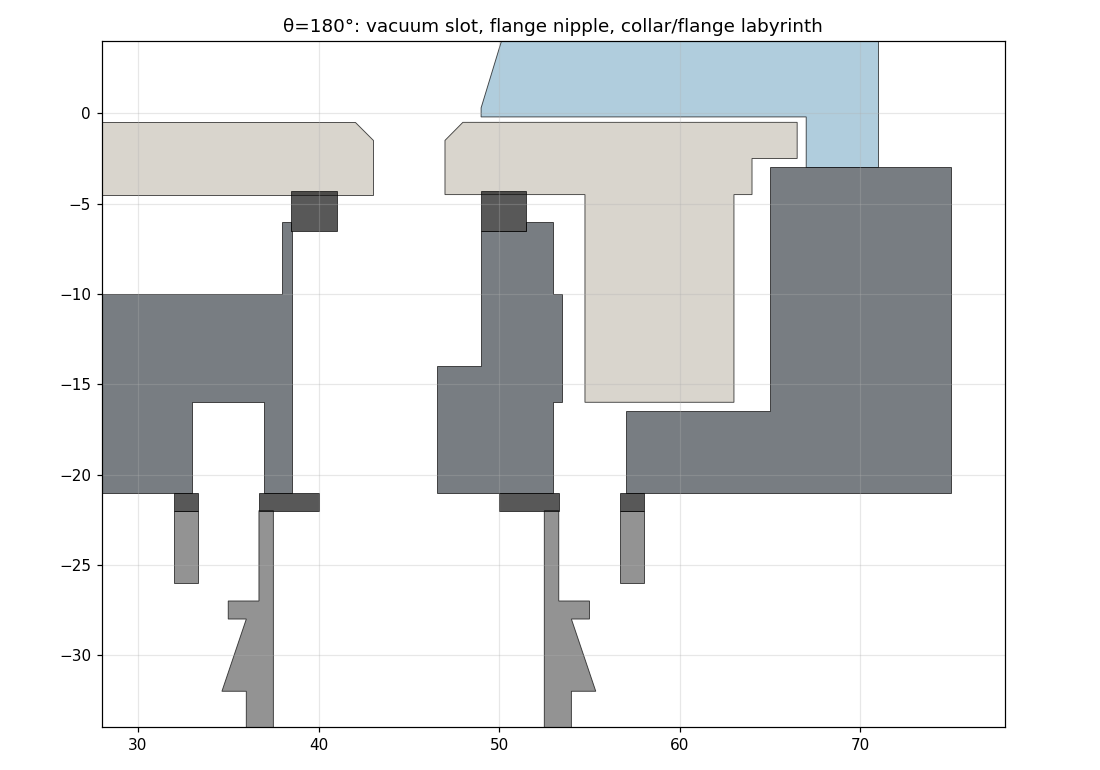
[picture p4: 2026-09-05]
docs/v7_section_theta180.png

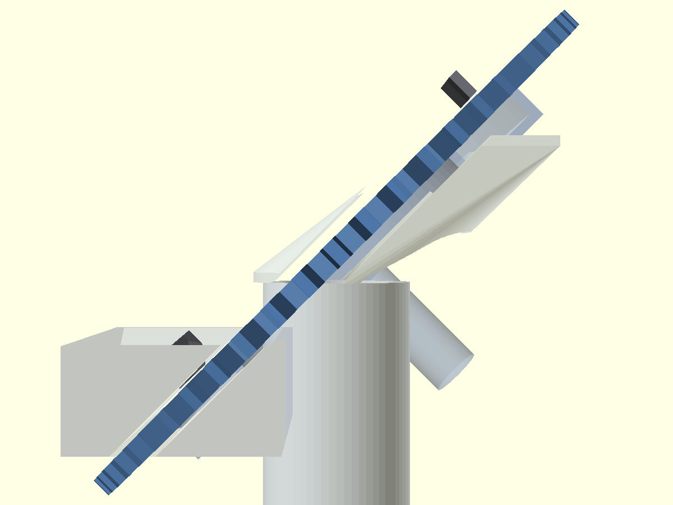
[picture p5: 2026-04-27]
renders/v5_4_anchor/side_x.png

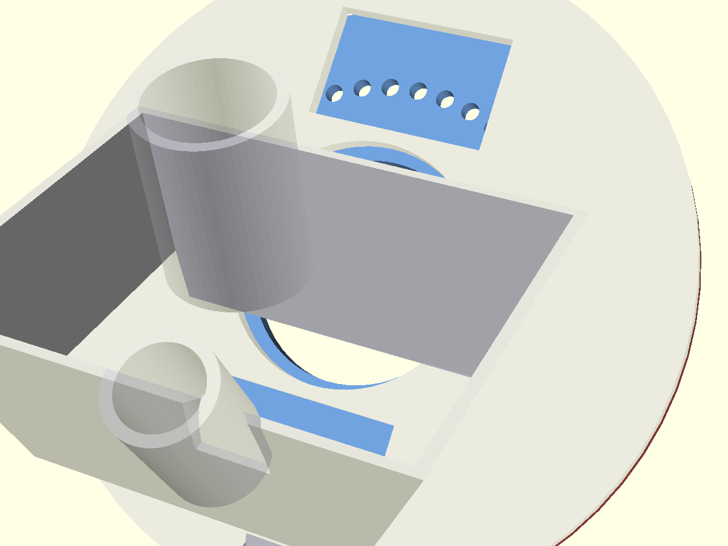
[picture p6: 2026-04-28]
renders/v5_7/v5_7_iso.png

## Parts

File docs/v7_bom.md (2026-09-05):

# SeedAI3D v7 bench seed counter — bill of materials

Quantities for one element on the bench stand. Prices are indicative September 2026 ranges from
hobby suppliers, not quotes.

## A. Printed parts (stl/v7/)

| Part | Qty | Material | Volume at 100 % | Notes |
|---|---|---|---|---|
| plate | 1 | PETG, 100 % infill | 178 cm³ (~225 g) | vacuum part |
| disc | 1 per crop | PETG, 100 % | 72 cm³ (~90 g) | 32 × Ø4 for soybean; edamame/snap bean discs differ only in hole count/diameter |
| collar | 1 | PETG (clear optional), 30 % infill fine | 152 cm³ | not a vacuum part |
| cover | 1 | clear PETG | 49 cm³ | |
| funnel | 1 | PETG | 11 cm³ | |
| pinion | 1 | PETG or nylon | 6 cm³ | |
| gasket | 1 | TPU 90A | 2 cm³ | chamber + blow-off frames |
| nipple + nipple_gasket | 1 + 1 | PETG + TPU | 4 cm³ | |
| blow_nipple | 1 | PETG | 1 cm³ | |
| sensor_elbow | 1 | black PETG | 17 cm³ | |
| feed_tube | 1 | PETG | 11 cm³ | |
| hopper | 1 | clear PETG | 47 cm³ | |
| singulator | 1 | PETG | 1 cm³ | |
| stand_bracket | 2 | PETG or 8 mm plywood | 86 cm³ each | |
| board_tray | 1 | PETG | 31 cm³ | |

Filament: ~0.8 kg PETG (100 % on plate and disc, 30 % elsewhere), ~10 g TPU. About 45 h
of printing at 0.2 mm; the plate alone is 10–12 h.

## B. Drive and vacuum

| Item | Qty | Spec | ~€ |
|---|---|---|---|
| NEMA17 stepper | 1 | 1.5–1.7 A, 40 mm body, 5 mm D shaft (e.g. 17HS4401 class) | 10–15 |
| Blower | 1 | 12 V car-vacuum-class motor (60–100 W) or small side-channel blower: 30–50 mbar at 5–10 L/s | 20–60 |
| Bleed valve | 1 | ball valve or gate valve on a 19 mm tee | 5 |
| Vacuum hose | 1 m | 19 mm ID, reinforced | 5 |
| Blow-off hose | 0.5 m | 8 mm ID, to a tee on the blower exhaust, or left open to atmosphere for the first build | 2 |
| Pressure sensor | 1 | 0–10 kPa differential/vacuum, analogue or I2C (MPXV5010DP / XGZP6847 class) | 5–12 |
| Tap tubing | 0.3 m | 3 mm silicone | 1 |

## C. Sensing

| Item | Qty | Spec | ~€ |
|---|---|---|---|
| IR emitter, 5 mm, 940 nm | 2 | 20 mA class | 1 |
| IR receiver, 5 mm | 2 | phototransistor, or TSSP4038-class modulated receivers (then drive the LEDs at 38 kHz) | 2–4 |
| Resistors | 4 | 150 Ω (LED), 10 kΩ (pull-up) | – |
| Hall sensor | 1 | SS49E (analogue) or A3144 (switch), TO-92 | 1 |
| Magnet | 1 | Ø6 × 2 mm neodymium, in the disc ring | 1 |
| Bag switch | 1 | miniature microswitch with lever | 1 |
| Load cell + amplifier (recommended) | 1 | 500 g bar cell + HX711 | 5–8 |

## D. Electronics

| Item | Qty | Spec | ~€ |
|---|---|---|---|
| Controller | 1 | FYSETC E4 (ESP32, 4 × TMC2209, BLE/Wi-Fi, 12–24 V). Alternatives: MKS TinyBee; Mega 2560 + RAMPS 1.4 + 4 × TMC2208 + 12864 LCD | 40–55 |
| Blower switch | 1 | 30 A automotive relay or 15 A MOSFET module driven from the board fan output | 3–6 |
| Power supply | 1 | 12 V 15 A (board + motor + blower), or 12 V 3 A for the board and a separate 12 V 10 A for the blower | 20–35 |
| TF card | 1 | 8–32 GB, for the bag log and sowing list | 5 |
| Push buttons | 2 | 22 mm panel buttons, green (start) and orange (empty), with LED ring if you like | 6 |
| Wiring | – | XH2.54 leads for motor and endstops, 0.5 mm² for the blower, 5 V and 12 V distribution | 10 |
| Console (option A) | 1 | any phone/laptop with Chrome or Edge; the viewer page over Web Bluetooth | 0 |
| Console (option B) | 1 | Raspberry Pi 4 + official 7" touchscreen, kiosk browser, USB serial or BLE to the board | 120–150 |

## E. Hardware and consumables

| Item | Qty | Use |
|---|---|---|
| M3 heat-set inserts | 7 | 3 in the wall top (cover/collar), 2 in the collar top (singulator), 2 in the plate back (nipple flange) |
| M3 × 8 | 4 | motor to plate, from inside the pinion pocket |
| M3 × 30 | 3 | cover through collar into the wall inserts |
| M3 × 10 | 4 | nipple flange (2), singulator (2) |
| M3 × 5 grub | 1 | pinion on the D shaft |
| M3 × 6 + standoffs | 4–6 | board on the tray |
| M6 × 25 bolts, washers, nyloc nuts | 4 | plate to stand brackets |
| M6 × 40 or wood screws | 4 | brackets to base |
| M4 × 16 wood screws | 4 | board tray to base |
| Plywood | 1 | 300 × 250 × 18 mm base |
| Hose clamps 19 mm | 2–3 | blower, tee, nipple |
| CA glue | – | feed tube into collar, blow nipple |
| Epoxy (thin) | – | only if the leak test fails: brush the chamber and slot |
| Sandpaper 400 grit + glass plate | – | flatten the disc back |
| Soapy water, 0.01 g balance, 20 seed bags | – | leak test and the 20 × 100-seed accuracy test |

Indicative total without the Pi console: €180–260 plus filament and plywood.

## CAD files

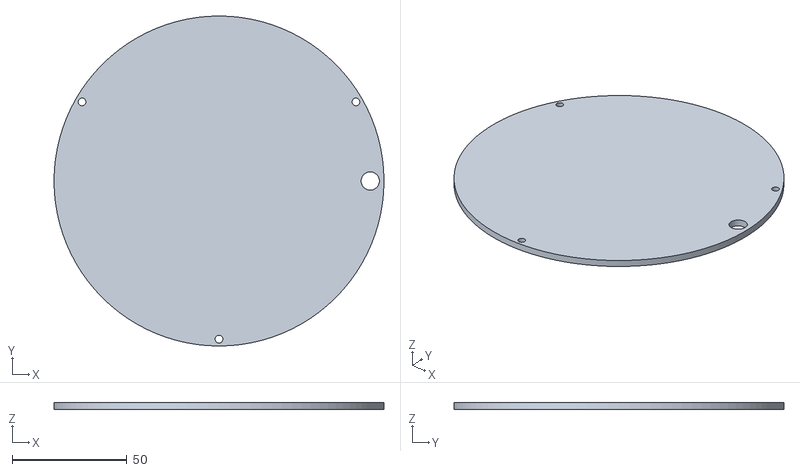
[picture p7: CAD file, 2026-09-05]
stl/v7/cover.stl
144.0 x 144.0 x 3.00

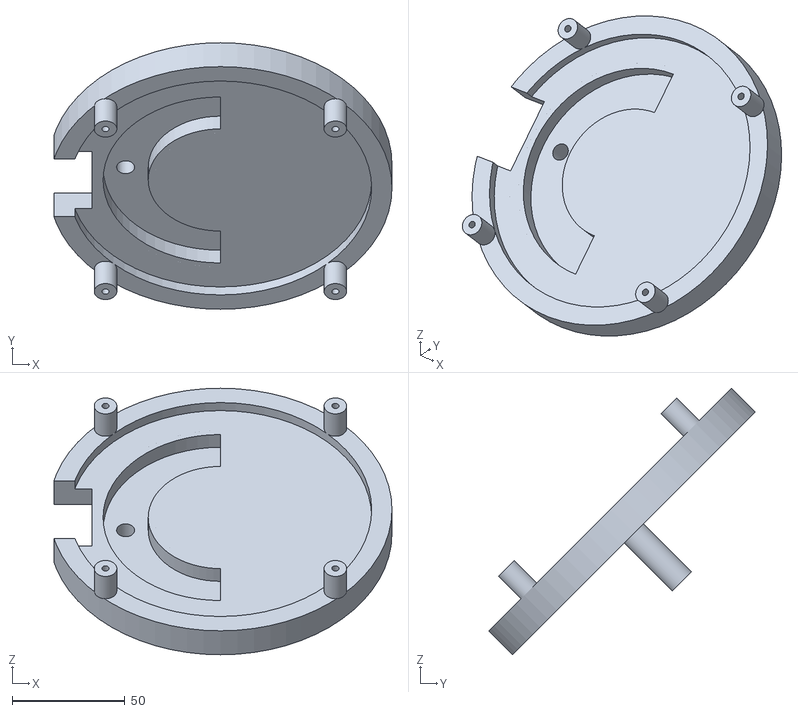
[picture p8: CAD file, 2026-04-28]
viewer/models/mal_plate.stl
149.7 x 118.1 x 118.1

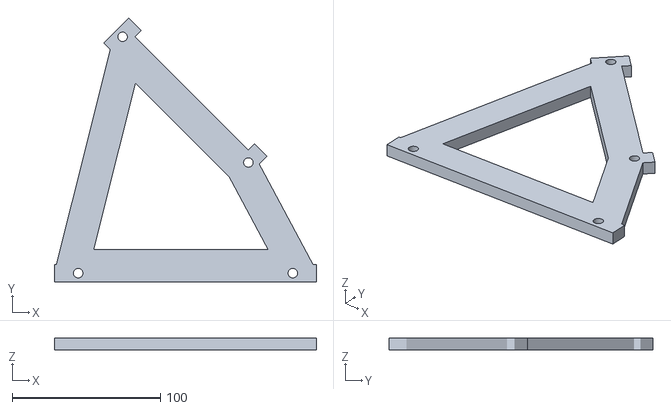
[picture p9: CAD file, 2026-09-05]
stl/v7/stand_bracket.stl
176.9 x 178.3 x 8.00

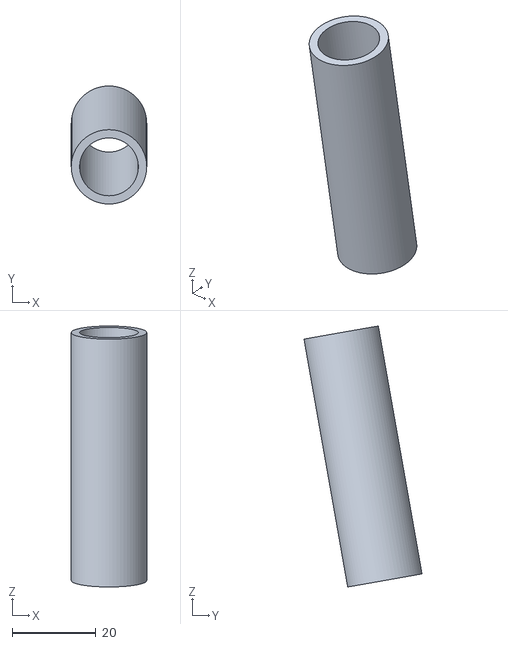
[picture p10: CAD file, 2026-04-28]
viewer/models/vac_tube.stl
18.0 x 28.1 x 62.2

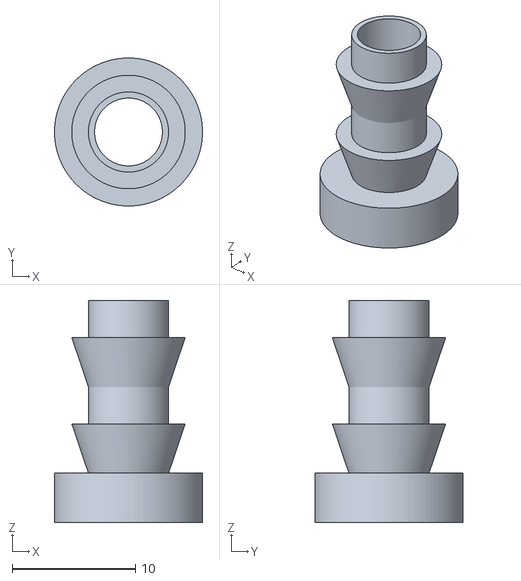
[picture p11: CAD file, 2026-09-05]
stl/v7/blow_nipple.stl
12.0 x 12.0 x 18.0

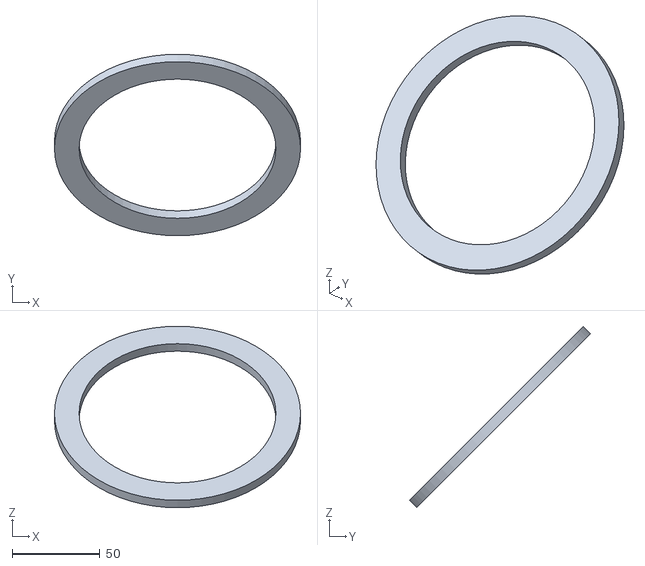
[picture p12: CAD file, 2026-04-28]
viewer/models/lid.stl
140.0 x 103.2 x 103.2

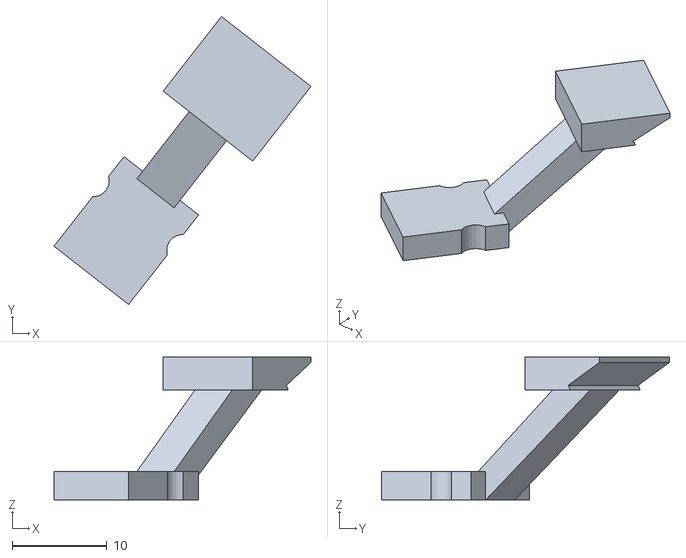
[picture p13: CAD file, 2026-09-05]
stl/v7/singulator.stl
27.1 x 30.4 x 15.1

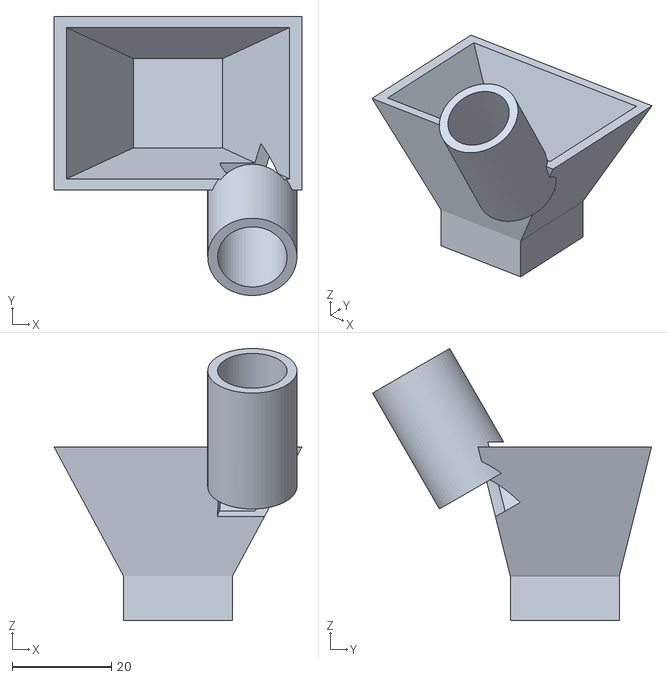
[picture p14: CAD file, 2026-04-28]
viewer/models/hopper.stl
50.0 x 56.3 x 54.9

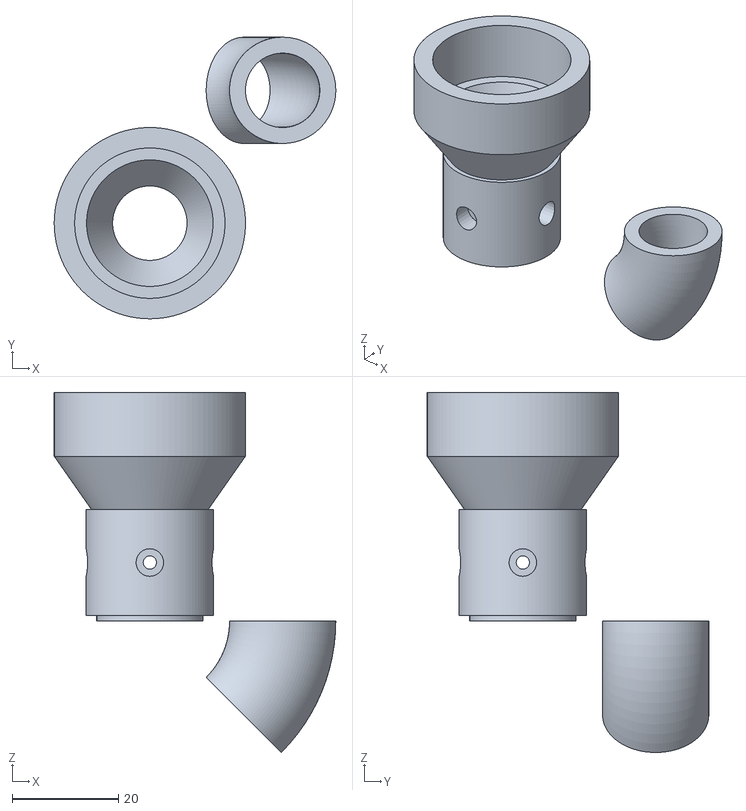
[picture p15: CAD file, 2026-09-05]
stl/v7/sensor_elbow.stl
53.0 x 53.0 x 67.7

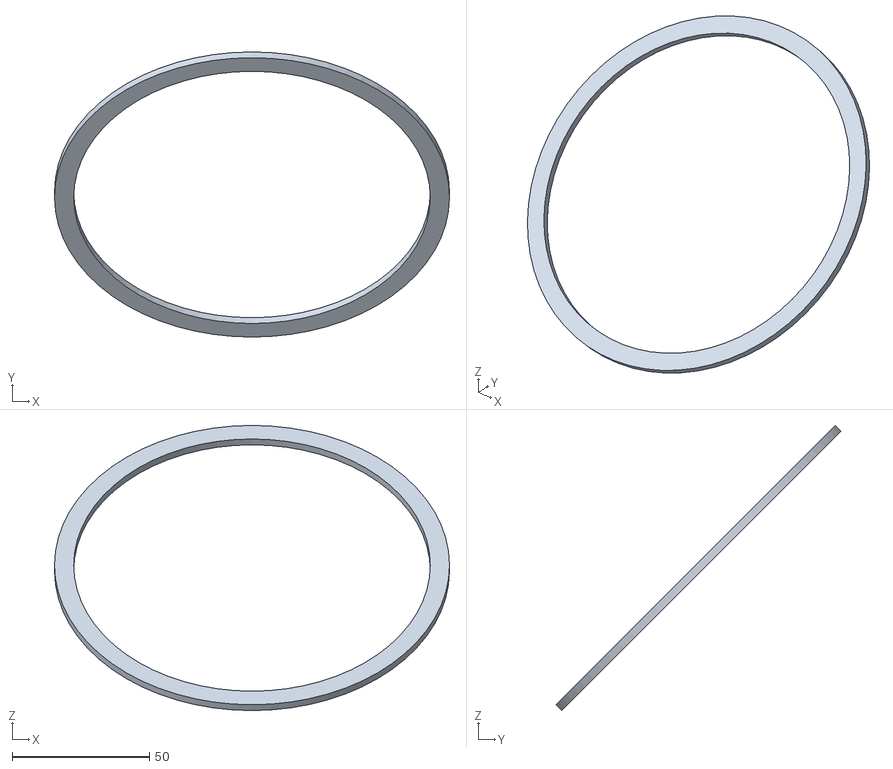
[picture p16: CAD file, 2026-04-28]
viewer/models/dust_ring.stl
144.0 x 103.9 x 103.9

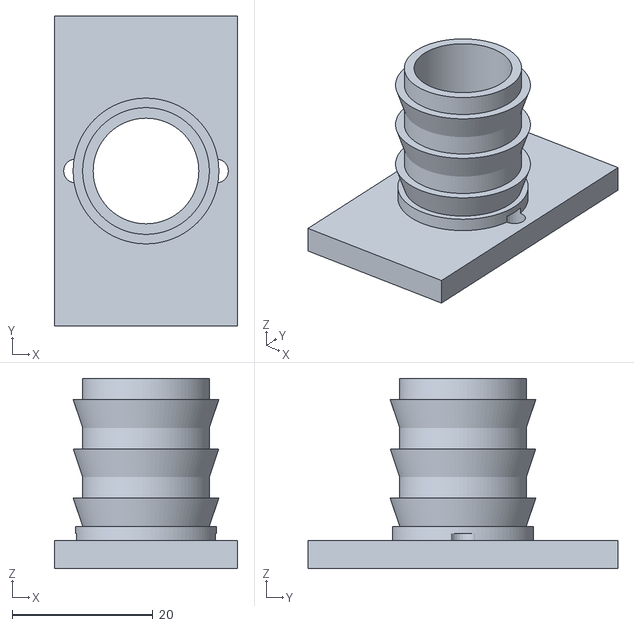
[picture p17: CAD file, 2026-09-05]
stl/v7/nipple.stl
26.0 x 44.0 x 27.0

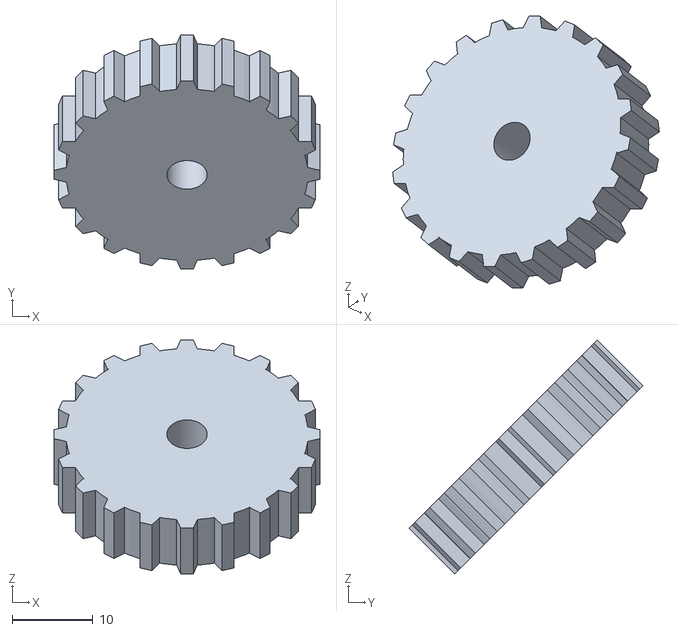
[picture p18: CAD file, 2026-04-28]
viewer/models/pinion.stl
33.0 x 29.0 x 29.0

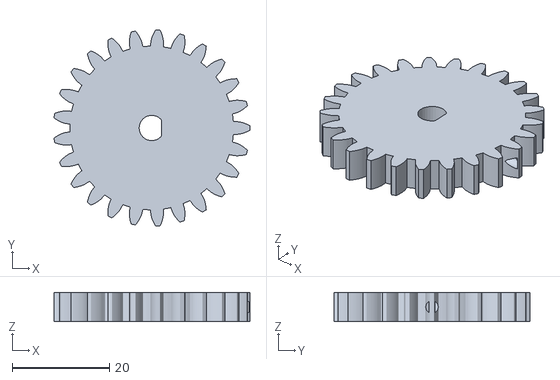
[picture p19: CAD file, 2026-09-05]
stl/v7/pinion.stl
40.4 x 40.5 x 6.00

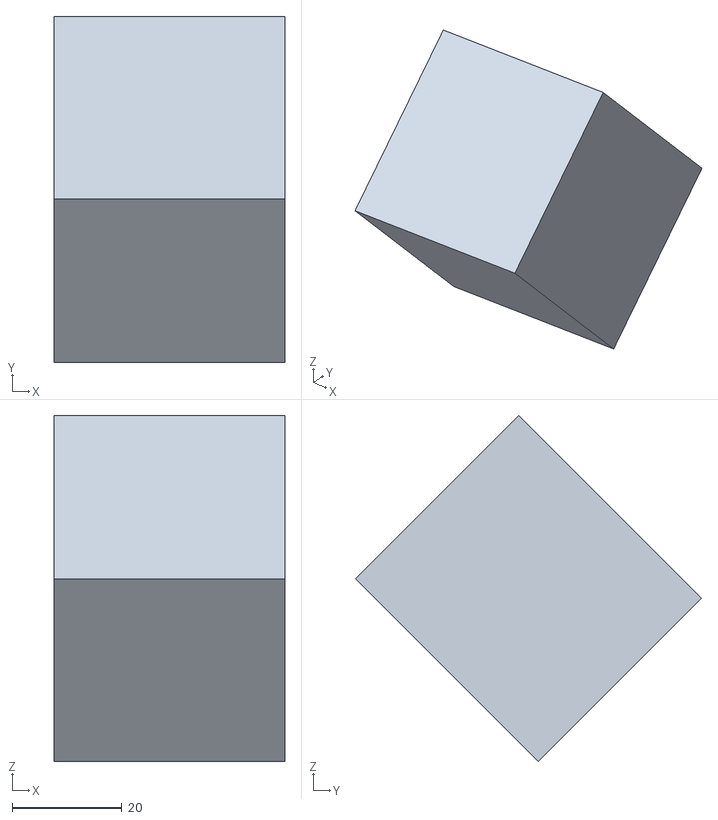
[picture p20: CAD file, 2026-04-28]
viewer/models/motor.stl
42.0 x 62.9 x 62.9

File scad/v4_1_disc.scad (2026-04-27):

// PROTISEM V4 — Phase 1: parametric disc
// Disc OD 120 (excl teeth), 132 (incl), thickness 4, central hole 50,
// 40 pickup holes (Ø 2.5) on R=42, 60 trapezoidal teeth on rim.
// Disc tilted 45° around X axis -> normal = (0, -sin45°, cos45°).

include <lib/parameters.scad>;
use     <lib/helpers.scad>;

// Customizer: set true to render the disc with the +Y half cut away
ENABLE_CROSS_SECTION = false;
// Customizer: set true for clean STL export (strips debug markers/colors)
EXPORT_MODE = false;

// ----- one trapezoidal tooth, base on circle R=DISC_OD/2 -----
module tooth(angle_deg) {
    pitch_deg = 360 / TOOTH_COUNT;       // = 6°
    bw = pitch_deg * TOOTH_BASE_FRACTION;
    tw = pitch_deg * TOOTH_TIP_FRACTION;
    r0 = DISC_OD / 2;
    r1 = DISC_OD_WITH_TEETH / 2;
    rotate([0, 0, angle_deg])
        linear_extrude(height = DISC_THICKNESS, center = true)
            polygon(points = [
                [r0 * cos(-bw/2), r0 * sin(-bw/2)],
                [r0 * cos(+bw/2), r0 * sin(+bw/2)],
                [r1 * cos(+tw/2), r1 * sin(+tw/2)],
                [r1 * cos(-tw/2), r1 * sin(-tw/2)],
            ]);
}

module tooth_ring() {
    pitch_deg = 360 / TOOTH_COUNT;
    for (i = [0 : TOOTH_COUNT - 1])
        tooth(i * pitch_deg);
}

// ----- pickup hole pattern (in pre-tilt frame, holes along Z = disc normal) -----
module pickup_holes() {
    for (i = [0 : PICKUP_HOLE_COUNT - 1]) {
        a = i * 360 / PICKUP_HOLE_COUNT;
        translate([PICKUP_HOLE_RADIUS * cos(a),
                   PICKUP_HOLE_RADIUS * sin(a),
                   0])
            cylinder(d = PICKUP_HOLE_DIA,
                     h = DISC_THICKNESS + 2,
                     center = true);
    }
}

// ----- disc body (flat in XY plane, normal = +Z) -----
module disc_flat() {
    difference() {
        union() {
            cylinder(d = DISC_OD, h = DISC_THICKNESS, center = true);
            tooth_ring();
        }
        // central seed-drop hole
        cylinder(d = CENTRAL_HOLE_DIA,
                 h = DISC_THICKNESS + 2,
                 center = true);
        // 40 pickup holes, perpendicular to disc plane
        pickup_holes();
    }
}

// ----- disc tilted into final orientation -----
module disc() {
    rotate([DISC_TILT_DEG, 0, 0]) disc_flat();
}

// ----- main render -----
if (EXPORT_MODE) {
    disc();
} else {
    cross_section_y(ENABLE_CROSS_SECTION)
        petg_blue() disc();

    // Debug markers (only shown without cross section)
    if (!ENABLE_CROSS_SECTION) {
        color("red")    translate(PICKUP_POS)  sphere(d = 4);
        color("orange") translate(RELEASE_POS) sphere(d = 4);
    }
}

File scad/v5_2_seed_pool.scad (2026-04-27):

// PROTISEM V5 — Phase 2: bottom seed-pool (vacuum pickup architecture).
//
// V4 (gravity-fed top reservoir, funnel above pickup) is RETIRED. V5 puts
// the seed reservoir as an OPEN BOWL beneath the disc; the disc-rim dips
// into the seed pool at θ=270° and vacuum behind the disc draws a single
// seed against the disc FRONT face. The seed rides the disc 180° around
// to θ=90° (release, directly above the central drop hole).
//
// Reference: Monosem MS, MaterMacc MS-300, Precision Planting vSet.
//
// Pool geometry (mm, world coords):
//
//     X-extent:  ±30                        (pool centred on x=0)
//     Y-extent:  -50 to -10                 (centred on disc-bottom y line)
//     Z-extent:  -45 (floor) to -25 (top)   (20 mm deep)
//     wall:      2 mm
//     bottom:    V-trough, 6 mm wide along disc-rim path
//
// The pool side walls (X=±30) sit INSIDE the disc-body sweep (the disc-body
// extends to |x| ≈ 50 at world z=-25). To let the disc pass through cleanly,
// we subtract the disc envelope from the pool — this carves a slot at each
// side wall. Real hardware will need brushes/wipers to seal the slot; the
// SCAD model is conceptual.
//
// Math sanity (worth keeping):
//
//     Disc-rim lowest world Z (α=270°, z_l=-2)
//         = R·sin(270°)·sin(45°) - (t/2)·cos(45°)
//         = -42.43 - 1.414  =  -43.85 mm
//     Pool floor at z = -45  →  rim-floor gap = 1.15 mm (tight; raise floor
//     in a future revision if seed bed needs >5 mm headroom).
//
//     Disc-FRONT face at α=270° (mid-plane + (t/2)·DISC_FRONT_NORMAL)
//         = (0, -29.70, -29.70) + (0, +1.414, -1.414)
//         = (0, -28.28, -31.11)
//     Seed top when full ≈ z=-32  →  seeds touch disc front face directly.
//
// Acceptance: pool watertight; disc and pool coexist (slot subtraction
// produces no spurious holes through the floor or front/back walls).

include <lib/parameters.scad>;
use     <lib/helpers.scad>;
use     <v4_1_disc.scad>;

// ----- customizer flags -----
ENABLE_CROSS_SECTION = false;
EXPORT_MODE          = false;
EXPORT_PART          = "all";   // "disc", "seed_pool", or "all"

// ----- pool primitives -----
EPS = 0.01;

// v5.5.2: half-disc body. Cylinder of R_OUTER, minus the y>0 half.
// Pool wraps the disc bottom 180° in plan view.
module seed_pool_outer_solid() {
    translate([0, 0, (SEED_POOL_Z_TOP + SEED_POOL_Z_FLOOR) / 2])
        difference() {
            cylinder(r = SEED_POOL_R_OUTER,
                     h = SEED_POOL_DEPTH, center = true);
            translate([-SEED_POOL_R_OUTER - 1, 0,
                       -SEED_POOL_DEPTH / 2 - 1])
                cube([2 * SEED_POOL_R_OUTER + 2,
                      SEED_POOL_R_OUTER + 1,
                      SEED_POOL_DEPTH + 2]);
        }
}

// Cavity: hull from a half-disc top opening down to a small V-cone patch
// centred at (0, SEED_POOL_Y_CENTER) — the V-cone position is unchanged
// from v5.5.1 because Y_CENTER=-30 gives the steepest front+back wall
// slopes given the half-disc footprint (front 52°, back 47°). Side walls
// curve outward to ±R_INNER and have shallower slopes (~28°), flagged in
// the build log; soybeans roll fine on 28° but a future revision could
// tighten R_OUTER or add a curved trough along the disc rim path.
module seed_pool_cavity() {
    bottom_x = SEED_POOL_BOTTOM_X;
    bottom_y = SEED_POOL_BOTTOM_Y;
    hull() {
        // top opening — inner half-disc, slightly above wall top so cut is clean
        translate([0, 0, SEED_POOL_Z_TOP + 1])
            difference() {
                cylinder(r = SEED_POOL_R_INNER, h = EPS, center = true);
                translate([-SEED_POOL_R_INNER - 1, 0, -EPS * 2])
                    cube([2 * SEED_POOL_R_INNER + 2,
                          SEED_POOL_R_INNER + 1,
                          EPS * 4]);
            }
        // V-cone bottom (4×4 patch above floor)
        translate([0, SEED_POOL_Y_CENTER, SEED_POOL_Z_FLOOR + SEED_POOL_WALL])
            cube([bottom_x, bottom_y, EPS], center = true);
    }
}

// Disc swept-volume envelope (with 1 mm radial + 1 mm axial clearance).
// Used to carve a slot through the pool SIDE walls so the disc can dip in.
//
// IMPORTANT: the disc TEETH (at OD=132) dip to world z = -48 at α=270° —
// 3 mm BELOW the pool floor at z=-45. If we subtracted the unclipped
// envelope, it would carve a long slot through the floor and seeds would
// spill out. To keep the floor sealed in the digital model, we clip the
// envelope to z ≥ floor + 1 mm. The physical implication — that the teeth
// would mechanically saw into a real floor at z=-45 — is flagged in the
// build log; the proper fix is either lowering the floor to z ≈ -50 or
// removing the gear teeth from the disc (deferred to Phase 6 gear-drive).
module disc_envelope_above_floor() {
    intersection() {
        rotate([DISC_TILT_DEG, 0, 0])
            cylinder(d = DISC_OD_WITH_TEETH + 2,
                     h = DISC_THICKNESS + 2,
                     center = true);
        // Half-space z ≥ floor + 1 mm (leave floor untouched)
        translate([-200, -200, SEED_POOL_Z_FLOOR + 1])
            cube([400, 400, 400]);
    }
}

// =====================================================================
//  Front-face tube ports (feeder inlet + vac-cleanup outlet).
//  Each is anchored on the front face at (x_off, y_front, z_off) and
//  extends OUTWARD (-Y, +Z) at the specified elevation. Cylinder default
//  axis is +Z; rotate([90 - elev, 0, 0]) tilts it to (0, -cos elev,
//  +sin elev). Tube body overlaps the wall by SEED_POOL_WALL + EPS so
//  the union is watertight; the bore extends a few mm further inboard
//  to fully pierce the wall.
// =====================================================================
module front_tube_outer(x_off, z_off, elev_deg, od, length) {
    translate([x_off,
               SEED_POOL_Y_CENTER - SEED_POOL_Y / 2,
               z_off])
        rotate([90 - elev_deg, 0, 0])
            translate([0, 0, -SEED_POOL_WALL - EPS])
                cylinder(d = od, h = length + SEED_POOL_WALL + EPS);
}

module front_tube_bore(x_off, z_off, elev_deg, id, length) {
    translate([x_off,
               SEED_POOL_Y_CENTER - SEED_POOL_Y / 2,
               z_off])
        rotate([90 - elev_deg, 0, 0])
            translate([0, 0, -SEED_POOL_WALL - 5])
                cylinder(d = id, h = length + SEED_POOL_WALL + 10);
}

module feeder_tube_outer() {
    front_tube_outer(FEEDER_TUBE_X, FEEDER_TUBE_Z,
                     FEEDER_TUBE_ELEV_DEG,
                     FEEDER_TUBE_OD, FEEDER_TUBE_LENGTH);
}
module feeder_tube_bore() {
    front_tube_bore(FEEDER_TUBE_X, FEEDER_TUBE_Z,
                    FEEDER_TUBE_ELEV_DEG,
                    FEEDER_TUBE_ID, FEEDER_TUBE_LENGTH);
}
// =====================================================================
//  Vac-cleanup tube — TOP-mount, near-vertical (80° elev). Mouth INSIDE
//  the pool at MOUTH_Z (= floor + 7 mm); tube extends DOWN to mouth and
//  UP for hose attach. Tilts -Y from vertical so upper end is on the
//  operator side (reachable with shop-vac hose) and tube body stays clear
//  of disc body slab (mouth eq=+8.5; seed-side, off the disc).
// =====================================================================
VAC_CLEAN_TUBE_TOTAL_LEN = VAC_CLEAN_TUBE_LENGTH_IN + VAC_CLEAN_TUBE_LENGTH_OUT;

module vac_clean_tube_outer() {
    translate([VAC_CLEAN_TUBE_X,
               VAC_CLEAN_TUBE_Y,
               VAC_CLEAN_TUBE_MOUTH_Z])
        rotate([90 - VAC_CLEAN_TUBE_ELEV_DEG, 0, 0])
            cylinder(d = VAC_CLEAN_TUBE_OD,
                     h = VAC_CLEAN_TUBE_TOTAL_LEN);
}

module vac_clean_tube_bore() {
    translate([VAC_CLEAN_TUBE_X,
               VAC_CLEAN_TUBE_Y,
               VAC_CLEAN_TUBE_MOUTH_Z - 1])
        rotate([90 - VAC_CLEAN_TUBE_ELEV_DEG, 0, 0])
            cylinder(d = VAC_CLEAN_TUBE_ID,
                     h = VAC_CLEAN_TUBE_TOTAL_LEN + 5);
}

module seed_pool() {
    difference() {
        union() {
            seed_pool_outer_solid();
            feeder_tube_outer();
            vac_clean_tube_outer();
        }
        seed_pool_cavity();
        feeder_tube_bore();
        vac_clean_tube_bore();
        disc_envelope_above_floor();
    }
}

// ----- main render -----
if (EXPORT_MODE) {
    if      (EXPORT_PART == "disc")       disc();
    else if (EXPORT_PART == "seed_pool")  seed_pool();
    else                                   { disc(); seed_pool(); }
} else {
    cross_section_x(ENABLE_CROSS_SECTION) {
        petg_blue() disc();
        petg_grey() seed_pool();
    }
    if (!ENABLE_CROSS_SECTION) {
        color("red")    translate(PICKUP_POS)  sphere(d = 4);   // pickup
        color("orange") translate(RELEASE_POS) sphere(d = 4);   // release
    }
}

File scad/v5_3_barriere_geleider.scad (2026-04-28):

// PROTISEM V5 — Phase 3: afstrijker (singulator blade) + geleider (catch-chute)
//                       + drop-tube (vertical exit through central hole).
//
// V5 architecture (D6): vacuum picks seeds from bottom pool at θ=270°, seeds
// ride disc-front-face 180° to release at θ=90°, free-fall lands at world
// (~1.7, 29.7, 0) — completely outside the R=25 central hole. Without active
// redirection, every seed misses. The GELEIDER is therefore not ornamental:
// it physically catches seeds at the disc-top and routes them backward in
// -Y to a throat directly above the central drop hole.
//
// Three components in this phase:
//
//  AFSTRIJKER (Dutch: "stripper")
//      Flat blade just past pickup, mounted to housing, standing 8 mm proud
//      of the disc-front face. As a doubly-vacuumed seed (one in the hole,
//      one stacked on top) passes under it, the upper seed is knocked off.
//      Singulation function — without it, the disc would carry duplicates.
//
//  GELEIDER (Dutch: "guide")
//      Curved chute. Catch-mouth at (0, +30, 22) — just below the disc-top
//      release point — opens upward to receive falling seeds. Cavity
//      transitions (lofted hull) to a circular throat at (0, 0, 6), the
//      entrance to the drop-tube. Walls 2 mm.
//
//  DROP-TUBE
//      Vertical tube from geleider throat (z=6) down through disc central
//      hole (z=0) and out below the pool floor (z=-52). 30 mm OD, 24 mm ID.
//
// Critical clearances (computed below):
//
//      Disc-rim at θ=90°, R=66 (tooth tip): world (0, 46.67, 46.67).
//      Geleider catch-mouth -Y wall is at y=20, z=22-23. Closest disc point
//      sits at z=42, so vertical separation ≈19 mm — comfortable.
//
//      Drop-tube OD=30 vs central-hole ID=50 → 10 mm radial gap on each
//      side. Tube is loose-fit through the hole; no interference.
//
// Acceptance: all three parts watertight; no STL-level interference with
// disc or pool; geleider cavity reaches both openings (catch-mouth open,
// throat open).

include <lib/parameters.scad>;
use     <lib/helpers.scad>;
use     <v4_1_disc.scad>;
// use <v5_2_seed_pool.scad> — archived in Phase 7. Geleider doesn't actually
// reference any seed_pool module; the include was for combined-render
// convenience.

// ----- customizer flags -----
ENABLE_CROSS_SECTION = false;
EXPORT_MODE          = false;
EXPORT_PART          = "all";   // "afstrijker", "geleider", "drop_tube", "all"

EPS = 0.01;

// =====================================================================
//  AFSTRIJKER — flat blade tangent to disc rim at θ=AFSTRIJKER_THETA_DEG.
// =====================================================================
//
// Construction: build the blade in disc-local frame (XY-plane), tangent to
// the rim at angle θ. Then apply the disc tilt (45° around X) and translate
// to the rim point. The blade extends 8 mm along the disc-normal direction
// (above the front face).

module afstrijker_blade() {
    // Pre-tilt frame: disc lies in XY plane, normal +Z.
    // Place a slab whose long axis is tangent to a circle at radius R, at
    // pre-tilt angle θ. Start with translate(0, R, h) — that puts the slab
    // at angle 90° on the circle. Rotate by (θ - 90°) around Z to swing it
    // to angle θ. The slab's local X-axis (length) is then tangent to the
    // rim at θ. Slab height range in Z = [t/2+1, t/2+1+H] sitting OUT of
    // the disc top face (will be mirrored to the FRONT face by caller).
    rotate([0, 0, AFSTRIJKER_THETA_DEG - 90])
        translate([0, PICKUP_HOLE_RADIUS,
                   DISC_THICKNESS / 2 + AFSTRIJKER_HEIGHT / 2 + 1])
            cube([AFSTRIJKER_LENGTH,
                  AFSTRIJKER_THICKNESS,
                  AFSTRIJKER_HEIGHT],
                 center = true);
}

module afstrijker() {
    // FLIP (2026-04-27): removed mirror([0,0,1]). The blade now stays on
    // the SCAD top face (+Z pre-tilt). After rotate([DISC_TILT_DEG, 0, 0])
    // it ends up at world (+Y, +Z direction relative to rim point) — the
    // disc-back-normal side, which is the operator-visible side of the
    // disc and therefore (post-flip) the seed-attachment side. Same side
    // as the new attached seeds; the afstrijker can physically brush them.
    rotate([DISC_TILT_DEG, 0, 0])
        afstrijker_blade();
}

// =====================================================================
//  AFSTRIJKER 2 — release-zone pusher at θ=95° (5° before release).
// =====================================================================
//
// Same construction principle as the first afstrijker, but at θ=95°,
// shorter (12 mm) and lower (6 mm) — well-attached seeds should already
// be releasing here, so this blade only has to nudge the stragglers off
// the disc into the geleider catch-mouth (which sits directly below at
// y∈[20,40], z∈[18,22]). The blade's tangent direction at θ=95° points
// roughly into +X, so a seed wiped off the disc gets a push in -Y/-Z
// (toward the geleider mouth), not flung outward.

module afstrijker2_blade() {
    rotate([0, 0, AFSTRIJKER2_THETA_DEG - 90])
        translate([0, PICKUP_HOLE_RADIUS,
                   DISC_THICKNESS / 2 + AFSTRIJKER2_HEIGHT / 2 + 1])
            cube([AFSTRIJKER2_LENGTH,
                  AFSTRIJKER2_THICKNESS,
                  AFSTRIJKER2_HEIGHT],
                 center = true);
}

module afstrijker2() {
    // FLIP (2026-04-27): same as afstrijker — mirror removed so the blade
    // stays on the seed-attachment side of the disc.
    rotate([DISC_TILT_DEG, 0, 0])
        afstrijker2_blade();
}

// =====================================================================
//  GELEIDER — lofted hull from rectangular catch-mouth to circular throat,
//  with cavity that punches through both ends.
// =====================================================================

module geleider_outer() {
    hull() {
        // Top ring: rectangular, slightly larger than the cavity opening so
        // the wall thickness is built in (cavity will inset by GELEIDER_WALL).
        translate([0,
                   GELEIDER_MOUTH_Y_CENTER,
                   GELEIDER_MOUTH_Z + 1])
            cube([GELEIDER_MOUTH_X + 2 * GELEIDER_WALL,
                  GELEIDER_MOUTH_Y + 2 * GELEIDER_WALL,
                  2],
                 center = true);
        // Bottom ring: circular, OD = throat + 2*wall.
        translate([0, 0, GELEIDER_THROAT_Z + 1])
            cylinder(d = GELEIDER_THROAT_DIA + 2 * GELEIDER_WALL,
                     h = 2,
                     center = true);
    }
}

module geleider_cavity() {
    // Cavity hull. Top inset (so walls have thickness), but extends UPWARD
    // above the catch-mouth to ensure the top is open. Bottom inset to throat,
    // extends DOWNWARD past the throat to ensure the bottom is open.
    hull() {
        // Top: rectangular inner opening, extended upward
        translate([0,
                   GELEIDER_MOUTH_Y_CENTER,
                   GELEIDER_MOUTH_Z + 30])
            cube([GELEIDER_MOUTH_X,
                  GELEIDER_MOUTH_Y,
                  EPS],
                 center = true);
        // Bottom: circular throat, extended downward
        translate([0, 0, GELEIDER_THROAT_Z - 30])
            cylinder(d = GELEIDER_THROAT_DIA, h = EPS, center = true);
    }
}

// Disc-envelope-with-clearance, used to carve a clean slot through the
// geleider so the disc passes through without interference. The lofted hull
// from a wide rectangular mouth to a narrow circular throat unavoidably
// crosses the disc body slab at intermediate z; carving the disc envelope
// out of the geleider opens a slot. The slot leaks seeds — same problem the
// seed pool has at its side walls — and the same fix applies in later
// phases (Monosem-style sealing brushes around the disc rim).
module disc_envelope_for_geleider() {
    rotate([DISC_TILT_DEG, 0, 0])
        cylinder(d = DISC_OD_WITH_TEETH + 2 * GELEIDER_DISC_CLEARANCE,
                 h = DISC_THICKNESS + 2 * GELEIDER_DISC_CLEARANCE,
                 center = true);
}

module geleider() {
    difference() {
        geleider_outer();
        geleider_cavity();
        disc_envelope_for_geleider();
    }
}

// =====================================================================
//  DROP-TUBE — straight vertical pipe.
// =====================================================================
module drop_tube() {
    h = DROP_TUBE_Z_TOP - DROP_TUBE_Z_BOTTOM;
    translate([0, 0, DROP_TUBE_Z_BOTTOM])
        difference() {
            cylinder(d = DROP_TUBE_OD, h = h);
            translate([0, 0, -1])
                cylinder(d = DROP_TUBE_ID, h = h + 2);
        }
}
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

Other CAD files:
stl/v7/feed_tube.stl
viewer/models/afstrijker2.stl
stl/v7/funnel.stl
viewer/models/afstrijker.stl
scad/v5_4_vacuum_chamber.scad
scad/archive/v5_4_vacuum_chamber.scad
scad/archive/v5_5_recovery_bowl.scad
scad/v5_5_recovery_bowl.scad
scad/v5_6_disc_mal.scad
scad/v5_7_housing.scad
scad/v7/seedai3d_v7.scad
stl/v4_1/disc.stl
stl/v5_2/disc.stl
stl/v5_3/afstrijker.stl
stl/v5_3/afstrijker2.stl
stl/v5_3/drop_tube.stl
stl/v5_3/geleider.stl
stl/v7/board_tray.stl
stl/v7/collar.stl
stl/v7/disc.stl
stl/v7/gasket.stl
stl/v7/hopper.stl
stl/v7/nipple_gasket.stl
stl/v7/plate.stl
viewer/models/disc.stl
viewer/models/drop_tube.stl
viewer/models/geleider.stl

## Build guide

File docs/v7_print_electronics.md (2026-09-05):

# SeedAI3D v7 — print files, vacuum, electronics, counter robustness

Companion to `v7_proposal.md`. Everything here is in `scad/v7/seedai3d_v7.scad`; the STLs in
`stl/v7/` are exported from it in print orientation. All 17 meshes are watertight (trimesh);
the cross-sections in `v7_sections_chamber.png` and `v7_section_theta180.png` are cut from the
assembly-position exports and are what the z-stack claims were checked against.

## 1. Parts, orientation, material

| STL | Material | Orientation (as exported) | Notes |
|---|---|---|---|
| disc | PETG | front face on the bed, ring gear up | 32 × Ø4 holes with 1 mm chamfer; index magnet pocket Ø6.3×2.2 in the ring back |
| plate | PETG, 100 % infill, 4 perimeters | back face on the bed | every pocket opens upward, no support. Vacuum slot 8×30 mm, blow-off bore, pressure tap, NEMA17 pattern, 4 × M6 mounts at (±40, ±60), drain slot, hall pocket |
| gasket | TPU 90A | flat | two frames 2.5 wide × 2.2 thick in a 0.5 mm recess → 0.2 mm compression |
| funnel | PETG | front flange on the bed | inner cone 39° from vertical; two bayonet lugs behind the slab, quarter turn |
| collar | PETG (clear if you want to see the pool) | underside on the bed | inner edge R49, 73° face, orifice bore at 305°, two M3 for the singulator |
| cover | clear PETG | flat | Ø144 × 3, three M3×30 through collar into wall inserts |
| pinion | PETG or nylon | flat | 25 T m1.5 involute, 5 mm D bore, M3 grub |
| singulator | PETG | foot on the bed | finger 2.4 mm above a seated seed; shim under the foot to adjust |
| nipple + nipple_gasket | PETG + TPU | flange on the bed | flange plate with plenum over the slot, barb for 19 mm hose, 2 × M3 |
| blow_nipple | PETG | flange down | press-fit Ø12 spigot, glue |
| sensor_elbow | black PETG | socket on the bed | Ø28 socket, Ø14 throat with 4 × Ø5.2 pockets (2 crossed IR pairs), 45° bend to vertical |
| feed_tube | PETG | as exported | Ø25/21, glued into the collar bore |
| hopper | clear PETG | wide end on the bed | 70° walls, Ø25 outlet stub, no ledges |
| stand_bracket (×2) | PETG or plywood | flat | 45° tabs bolt to the plate mounts; base rail with two M6 |
| board_tray | PETG | flat | Mega 2560 and Raspberry Pi 3/4 hole patterns, cable window |

Print settings that matter for vacuum: 0.2 mm layers, 4 perimeters, 100 % infill on the plate
and disc, flow 102–104 % so perimeters fuse, no "gap fill" gaps. PETG, not PLA (creep under
the gasket load). Clean the disc back on 400-grit glass-backed paper so it is flat.

Not in this release: the field gate (hinged collar sector) and the row-unit bracket. The
bench collar is one piece.

## 2. Vacuum: tight where it matters, weak on purpose

**What holds a seed.** Holding force = Δp × hole area. Ø4 hole = 12.6 mm². At 30 mbar that
is 38 mN, about 20 × a soybean's weight (0.18 g). At 60 mbar it is 40 ×. Commercial soybean
discs run 40–55 mbar with the same hole size, but at 3–5 × our disc speed and with singulators
that push harder. For a bench counter at ≤ 20 rpm start at **25–30 mbar** and tune on the
doubles count; go up only if skips appear. The simulation in the viewer uses that assumption
(skips below ~25 mbar, doubles above ~40) as a placeholder until measured.

**How much air.** With no seeds seated, 16 holes are open over the chamber: 200 mm². At
30 mbar, air speed ≈ 70 m/s, Q ≈ 0.65 × 200 mm² × 70 m/s ≈ 9 L/s (550 L/min). With seeds
seated it drops to 2–3 L/s. So the blower must give 30–50 mbar at 5–10 L/s. That is a
12 V car-vacuum-class motor (60–100 W) or a small side-channel blower, throttled with a bleed
valve; a fan or a bilge blower (3–8 mbar) will not do, and a shop-vac (200 mbar) only with a
large bleed. The slot in the plate is 240 mm² so it never chokes.

**Where it leaks and what stops it.**

| Path | Measure |
|---|---|
| gasket → disc back | flat TPU frame in a 0.5 recess, 0.2 compression; vacuum itself pulls the disc onto the gasket with Δp × 1131 mm² ≈ 3.4 N at 30 mbar; extra drag torque < 0.01 N·m at the motor |
| chamber → ring-gear groove | island wall R49–53.5, 4.5 mm, solid from z −16.5 to −6 |
| chamber → centre | wall R38–41, 3 mm |
| chamber floor → pinion pocket | floor at z −14, pocket at ≤ −10.5, different radius |
| nipple → back face | flange plate with TPU flat gasket over the slot, 2 × M3 |
| print porosity | 4 perimeters, 100 % infill, over-extrusion; if the leak test fails, brush epoxy into the chamber and slot |
| pressure tap | Ø3 at θ=135°, silicone tube to a −10 kPa sensor (e.g. XGZP6847 class) or an analogue gauge |

**Leak test before anything else.** Print the plate and gasket only. Clamp a flat plate
(glass or the cover) over the land with the gasket in place, connect the blower through the
bleed valve, read the tap. If you cannot reach 40 mbar with the bleed closed, find the leak
with soapy water on the back face. Then fit the disc and read the drop with all holes open
versus all holes taped: that ratio is your seated-vs-open leakage and tells you the blower
margin. Log both numbers; they are the acceptance test for the print settings.

## 3. Electronics

**Board.** FYSETC E4: ESP32 with built-in Wi-Fi and Bluetooth, 4 × TMC2209, 12–24 V,
90 × 67 mm, TF card, 3 endstop inputs, one controllable fan output. One board covers the
bench counter (1 element) and, with the endstops used as IR gate inputs, up to 3 elements; the
MKS TinyBee (5 drivers, more inputs, also ESP32) covers a 4-element bar. Both run Arduino
framework code. The tray in `board_tray.stl` takes a Mega + RAMPS or a Raspberry Pi as well;
the E4 is small enough to sit on it with two extra holes.

**Blower.** On the fan MOSFET (12/24 V) or an external relay if the motor draws more than the
output rating. Bleed valve in the hose sets the pressure; the tap sensor displays it.

**Sensor.** Two crossed IR pairs (5 mm LED + phototransistor) in the Ø14 throat of the sensor
elbow. A Ø6 seed in a Ø14 bore cannot pass either beam without breaking it. Drive the LEDs
with a 10 kHz square wave and AC-couple the receivers (or use a modulated receiver like the
TSSP4038 family): ambient light and sunlight through the clear parts then do not matter, and
the black elbow already shades the throat. **It does not need darkness**; a plain unmodulated
phototransistor in a clear tube would, which is why the throat is black and separate.
Occlusion time at ~1 m/s is 5–8 ms for one seed; two seeds stacked give > 12 ms → counted as a
double and flagged.

**Index.** Ø6 × 2 magnet in the ring back, hall sensor (SS49E / A3144) in the plate pocket.
With it the firmware knows which hole is at the release point at every step and expects a gate
pulse in a ±10 ms window per hole: a missing pulse is a skip, a pulse outside any window is
noise, two in one window is a double. The Contador has no such reference; this is the single
biggest accuracy lever we have over a vibratory counter.

**Console.** No LCD on the board. The display is `viewer/v7/index.html` itself, connected over
Web Bluetooth (Chrome/Edge on Android, Windows, macOS, ChromeOS), or the same page in kiosk mode
on a Raspberry Pi with the 7" touchscreen, connected to the E4 over USB serial or BLE. The
card on the right of the page mirrors what the firmware sends and its buttons send the commands
below. The physical buttons on the stand are optional: Start (green), Empty (orange).

BLE protocol (Nordic UART UUIDs):
- service `6e400001-…`, command characteristic `6e400002-…` (write), status `6e400003-…` (notify)
- commands, JSON: `{"cmd":"count","n":30}`, `{"cmd":"empty"}`, `{"cmd":"stop"}`, `{"cmd":"gate"}`,
  `{"cmd":"rpm","v":12}`, `{"cmd":"target","n":30}`, `{"cmd":"vac_set","mbar":30}`
- status, JSON, 5 Hz: `{"mode":"COUNT","bag":12,"n":17,"target":30,"total":377,"rpm":12,"vac":1,"mbar":31,"doubles":2,"skips":1,"gate":0}`

Firmware modes are as in `v7_proposal.md` §6. Add: bag-presence switch on an endstop input
(no bag, no count), and log one CSV line per bag to the TF card: line, bag, n, doubles, skips,
mbar, timestamp.

## 4. Is the counting already robust enough?

What we have: singulation before the gate, two crossed beams, pulse-width doubles detection,
index-referenced expectation windows, a throat narrow enough that nothing passes unseen, and
a slow-down that leaves nothing in flight at the stop. That is more than the Contador's single
channel has. What we do not have is a measurement. The test is 20 runs of 100 counted seeds
weighed on a 0.01 g balance against the known thousand-kernel weight; the residual is the
error. Until then the accuracy is a design argument.

## 5. Ideas to reach parity with commercial counters

1. **Weigh the bag.** A 500 g load cell + HX711 under the bag holder (€5). Every bag gets a
   count *and* a mass, so TKW comes free and a bag whose mass is off by one seed is flagged.
   No commercial counter under €3000 does both.
2. **Bag carousel.** Eight bag holders on a servo-indexed ring under the exit, like the
   Contafill. "Next bag" then needs no hands at all; a line of 8 rows is one button.
3. **Line ID by barcode.** A USB barcode scanner into the Pi; the bag label is printed on a
   small thermal printer with line, N, mass, date. The SD CSV becomes the sowing plan.
4. **Crop presets.** Disc, mbar, rpm, singulator shim, throat insert, stored per crop and
   recalled by name; the console refuses to start if the index sees the wrong disc (hole count
   read from the pulse pattern in one empty revolution).
5. **Self-test at start.** One empty revolution with vacuum on: no gate pulses (noise check),
   pressure within band (leak check), index seen (disc seated). Three seconds, every session.
6. **Purge revolution between lines.** After EMPTY: vacuum off, one revolution with the
   blow-off pocket on positive pressure (reverse the blower or a second small pump) to clear
   any seed stuck in a hole.
7. **Auto-vacuum.** Servo on the bleed valve, closed loop on the tap sensor; the doubles and
   skips counters nudge the setpoint (skips → +2 mbar, doubles → −2 mbar) within limits.
8. **Two elements on one stand.** The board has four drivers; two elements side by side double
   the throughput and let one count while the other is being bagged.

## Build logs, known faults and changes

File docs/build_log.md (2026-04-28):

# PROTISEM V4 — Build Log

## Phase 1 — Parametric disc + viewer bootstrap (2026-04-27)

- Disc compiles to a watertight STL: 5928 vertices, 11920 faces, volume ~40.5 cm³.
- Bounding box matches expectation for a 132 mm OD disc tilted 45° around world X (132 × 96.2 × 96.2 mm).
- Volume sanity check passed. Centroid at origin (within 0.001 mm).
- Resolved spec ambiguity: the pickup-zone coordinate `(0, 29.7, 29.7)` requires tilt around world X, not Y. See `docs/decisions.md` D1.
- Viewer scaffolded with three.js (vendored, 1.3 MB) + OrbitControls + STLLoader. Z-up convention propagated to camera.
- Smoke test: all seven viewer assets serve 200 via `python3 -m http.server -d viewer`.

## Phase 2 — Reservoir + viewer integration (2026-04-27)

- Reservoir compiles watertight: hull from 60×60 top to Ø16 outer/Ø12 inner outlet, 80 mm tall, 2 mm wall.
- Validation caught my hand-math error: I sized clearance to the inner rim (Ø12) but the collision happens at the outer rim (Ø16 with the 2 mm wall). Bumped `RESERVOIR_OUTLET_CLEARANCE` 14 → 17 mm. Decision D4.
- Min disc-reservoir clearance now 6.5 mm (≥5 mm required), measured by trimesh proximity sampling 4000 surface points.
- Phase-2 cross-section uses the X-plane (cuts +X), not the Y-plane (Phase-1's choice). The reservoir lives entirely in +Y; cutting +Y would erase it.
- Viewer now loads `disc.stl` + `reservoir.stl`, renders the reservoir translucent grey, drops Ø6 yellow seed spheres from the outlet under (visualisation-scaled) gravity, lands them on the disc top plane (`z = y + 2.828`) within the disc body annulus (R 25–60), and removes them 1.5 s after landing.
- New "Seed feed" slider (0–10/s). All eight viewer assets still serve 200.

## Phase 2 fix — pickup/release positions corrected (2026-04-27)

- The V4 drawing's "Vooraanzicht schijf" panel shows pickup AND release both near the TOP of the disc, symmetric around the Y axis. The previous Phase-2 release marker at (0, −29.7, −29.7) was the disc's lowest point — wrong. Decision D5.
- Introduced `PICKUP_THETA_DEG = 110` and `RELEASE_THETA_DEG = 70` in `parameters.scad`, deriving world coordinates from `(R·cosθ, R·sinθ·cos45°, R·sinθ·sin45°)`.
- New marker positions:
  - PICKUP  (red)    = (−14.365, 27.907, 27.907)  θ=110°
  - RELEASE (orange) = (+14.365, 27.907, 27.907)  θ=70°
  - Both at world-Z = 27.9. Seed travels CCW the long way (~320°): pickup → bottom → release.
- Reservoir outlet shifted: now directly above PICKUP at (−14.365, 27.907, 35.000), 7.1 mm vertical above the pickup mid-plane. `RESERVOIR_OUTLET_CLEARANCE` 17 → 7.1.
- Rotation direction confirmed CCW (positive ω around DISC_AXIS): velocity at release is (0, +y, +z) — front-face-rises-on-the-release-side, matches Hendrik's "schijf draait aan voorzijde omhoog".
- **Validation regression:** with the smaller clearance, the +Y outer rim of the Ø16 outlet wall clips the disc at min = 0.10 mm @ (−19.7, 32.3, 35.0). All other checks pass. Three options to recover ≥5 mm: (a) raise outlet to z ≈ 45.8 (clearance back to ~17.9 mm), (b) shrink outlet to Ø6 inner / no flange and re-check, (c) tilt the outlet plane parallel to the disc. Pending Hendrik's call — see D5.

### Phase 3 physics note (deflector + funnel is mandatory, not optional)

At release (+14.4, 27.9, 27.9) and 5 RPM, the pickup hole's tangential speed is ω·R = (5·2π/60)·42 ≈ 22 mm/s. If the seed simply detaches and free-falls under gravity, it crosses z=0 at world (~12, 28, 0) — well outside the central hole (R=25 around origin). Conclusion: **a seed released without guidance misses the central hole** and lands on the back face of the disc. Phase 3 must therefore include a deflector ramp from the release zone toward the central hole; the trickle-funnel cannot be ornamental.

## Phase 2 V5 — architecture switch: top reservoir → bottom seed-pool (2026-04-27)

> Phase 2 V5: architectuur omschakeling van top-reservoir (V4) naar bottom
> seed-pool (V5) op verzoek van Hendrik. Reden: vacuum-pickup uit zaad-pool
> is conceptueel beter voor singulatie-precisie (Earthway/MaterMacc/Monosem
> patroon) en geeft betere kinetische voorwaarden bij pickup (zaad op
> snelheid 0). Wel architectureel ander dan V4-tekening — dit is V5 niet V4.

What changed:

- Pickup θ moved to **270°** (disc bottom, world (0, -29.7, -29.7)). Release θ moved to **90°** (disc top, world (0, +29.7, +29.7)). Both on X=0 plane.
- Travel arc is now **180°** along the disc rim, decreasing θ (Option 1 — front face rises into release).
- `scad/v4_2_reservoir.scad` deleted; replaced by `scad/v5_2_seed_pool.scad`.
- Pool: 60 × 40 × 20 mm open bowl, centred at (0, -30, -35). V-trough bottom (6 mm strip) so seeds gather along the disc-rim dip line.
- Disc-envelope subtraction carves slots through the X=±30 side walls so the disc can dip in. Floor and front/back walls stay sealed.
- `parameters.scad`, `validation/geometry_check.py`, viewer (markers, animation, UI) all rewritten.

Geometric findings worth flagging:

1. **Disc TEETH dip below pool floor.** Tooth tips at α=270°, z_l=-2 sit at world z=-48.09. Pool floor at z=-45 → 3.09 mm interference. The SCAD model clips the disc envelope to z ≥ floor+1 so the *digital* floor stays sealed, but a real disc spinning at 5 RPM would saw into a real floor at z=-45. Two clean fixes available:
   - Lower pool floor to z=-50 (5 mm clearance below tooth tips). Pool depth becomes 25 mm.
   - Remove gear teeth from the disc until Phase 6 (gear drive). Phase 1 disc would become OD=120 (no teeth).
   Validation flags this as `disc_above_floor: gap=-2.22 mm` — left failing on purpose so the choice is in front of Hendrik.

2. **Seed-pool side-wall slots leak.** Real Monosem/MaterMacc seeders use brushes/wipers around the disc to seal these slots so seeds don't escape. The SCAD model cuts clean slots; sealing is a Phase-3 (or later) concern.

3. **Released seed misses central hole.** At release (0, 29.7, 29.7), tangential velocity is ~22 mm/s in +X (5 RPM). Free-fall trajectory enters disc body at (0.5, 29.7, 26.9), r_local=40 (between central hole at R=25 and outer rim at R=60). Lands on disc back face. Same conclusion as before: Phase 3 deflector is non-negotiable.

Acceptance status:
- All Phase-1 disc checks: PASS.
- Pool checks (file/watertight/bbox/z_bounds/y_centre): PASS.
- `disc_above_floor`: FAIL by 2.22 mm — pending Hendrik's call (lower floor or strip teeth).

## Phase 3 V5 — afstrijker + geleider + lifecycle animation (2026-04-27)

Two changes bundled because they only make sense together:

1. **Afstrijker + geleider + drop-tube** added (the components originally
   planned for Phase 3). New SCAD file `scad/v5_3_barriere_geleider.scad`
   wires all three:

   - **Afstrijker** — flat blade (18×2×8 mm) tangent to disc rim at
     θ=250° (20° past pickup, per Phase-3 spec). Sits on the disc-front
     face, 7 mm offset along DISC_FRONT_NORMAL. World centroid
     (-14.36, -22.96, -32.86) — geometrically inside the seed-pool
     volume; the rim has not yet emerged from the pool at θ=250°. Spec
     wording is preserved; pool-emergence point is θ≈237.5°. Function:
     5% probability of knocking off attached seeds (singulation), in
     the viewer's animation only — physical SCAD is just a blade.
   - **Geleider** — lofted hull from rect catch-mouth (40×20 at z=20,
     y_center=30) to circular throat (Ø30 at z=-6, y=0). Walls 2 mm.
     Throat lowered from spec'd z=5 to z=-6 because a straight loft from
     z=20 to z=5 crosses the disc-body slab (|z-y| ≤ 2.83 mm) at
     intermediate z; lowering throat below the slab eliminates the
     interference at the path's centre. Disc-envelope-with-3 mm-clearance
     is also subtracted from the geleider (analogous to the seed-pool
     side-wall slots) to carve clean rotation room — slot leaks; sealing
     brushes deferred to a later phase.
   - **Drop-tube** — straight pipe Ø30 OD / Ø24 ID from geleider throat
     (z=-6) down to z=-52 (below pool floor). Fits Ø50 central hole with
     10 mm radial slop on each side.

2. **Seed-flow animation overhaul.** Phase-2 viewer steady-state showed
   "Pool 0 / On-disc 0 / Released 80" — pool drained in ~24 s and stayed
   empty. Two bugs fixed:

   - **Visibility.** Camera lives at world -Y. Physical disc-front face
     normal is +Y (seeds press against it from the pool). Attached seeds
     placed on the physical front face were on the FAR side of the disc
     and hidden behind it. Viewer now uses `DISC_FRONT_VIS = +DISC_NORMAL`
     for visualisation only — seeds appear on the camera-side face. The
     SCAD afstrijker stays on the real (physical) front face.
   - **Pool starvation.** Pool now refills automatically when it drops
     below 12 seeds, back up to 50. Animation runs indefinitely.

   Full lifecycle state machine:

   `pool → attached → falling → gliding → exiting → landed`

   plus the afstrijker's `attached → pool` knock-back transition. Per-state
   counters on the HUD: pool / on-disc / in-geleider / in-drop-tube
   (current totals) and sown / skipped / missed (cumulative). Fall →
   geleider catch is detected by AABB overlap with the catch-mouth bounds
   (x ∈ ±20, y ∈ [20, 40], z ∈ [16, 22]). Glide is a smoothstep lerp from
   catch position to throat (0.4 s vis time). Exit is a linear lerp down
   the drop-tube (0.35 s).

Acceptance status (geometry_check.py):
- Phase-1 disc, Phase-2 pool: PASS.
- Phase-3 afstrijker (file/watertight/centroid-at-θ=250-on-front-face): PASS.
- Phase-3 geleider (file/watertight/z-bounds/x-extent/disc-clearance≥3 mm): PASS.
- Phase-3 drop-tube (file/watertight/z-bounds/fits-central-hole): PASS.
- `disc_above_floor`: still FAIL by ~2.2 mm — open D6 question, unchanged.

All eleven viewer assets serve 200 (disc + pool + afstrijker + geleider +
drop_tube STLs, plus index.html / viewer.js / styles.css / three.module.js
+ OrbitControls + STLLoader).

## Phase 3 V5 visual fixes — seed offset, raised pool, release pusher (2026-04-27)

Three small visual issues from Hendrik's first-pass review of the Phase-3
animation, fixed in one update:

1. **Seed offset 5 mm in disc-front-normal direction.** Attached red seeds
   were rendering with their centres on the disc mid-plane, which made them
   look embedded in the disc face. Bumped `SEED_OFFSET` from `SEED_RADIUS`
   (3 mm) to a fixed 5 mm so the sphere's near pole lightly touches the disc
   surface and most of the sphere is visible in front. Direction unchanged
   (`DISC_FRONT_VIS = (0, -sin45°, +cos45°)`, the camera-facing face).

2. **Seed-pool raised 8 mm.** Pool floor `−45 → −37`, walls top `−25 → −17`,
   fill line `−32 → −24`. The pool seed pile (top now at z≈−24) sits well
   above the disc tooth-rand sweep at θ=270° (z≈−46.7), so seeds no longer
   visually overlap with the teeth. Disc-rim mid-plane (z=−29.7) still dips
   ~12.7 mm into the open pool, so vacuum pickup at θ=270° still passes
   through seed mass.

   *Side effect on D6 floor-clearance:* the disc tooth tip at α=270° (world
   z=−47.82) now sits 10.82 mm BELOW the raised pool floor at z=−37 (was
   2.22 mm). The validator still reports `disc_above_floor: gap=−10.82 mm`
   — the SCAD model still digitally seals the floor by clipping the disc
   envelope subtraction, but the physical interference is now larger. D6's
   open question (lower the floor below tooth tips OR strip teeth until
   Phase 6) is more pressing; Hendrik's call still pending.

3. **Second afstrijker at θ=95°** (5° before the natural release at θ=90°).
   New SCAD module `afstrijker2()` — same construction as the first blade,
   but shorter (12 mm) and lower (6 mm). Centroid (−3.66, +33.83, +25.34)
   matches expected within 0.00 mm. Function in the viewer: ~10% probability
   per pass that an attached seed passing under it gets "pushed" off the
   disc straight into the geleider catch-mouth (skipping the falling state),
   visualising the redundancy against imperfect vacuum cutoff. New
   `savedCount` counter tracks pushed-and-saved seeds. Both afstrijkers are
   now individually toggleable in the controls panel.

Acceptance status (geometry_check.py):
- All Phase-1 / Phase-2 / Phase-3 component checks PASS, including the new
  `centroid_at_θ=95_on_front_face` check on afstrijker2.
- `disc_above_floor`: now FAIL by 10.82 mm (was 2.22 mm before raised pool).
  Pre-existing D6 issue, unchanged in spirit, magnified by visual fix.

All twelve viewer assets serve 200 (now adds afstrijker2.stl).

## Phase 3 V5 fix — FRONT_NORMAL derived from pool reference (2026-04-27)

The previous attempt placed attached seeds along `DISC_FRONT_VIS = +DISC_NORMAL
= (0, -sin45°, +cos45°)`, justified at the time as a "visibility hack" because
seeds on the physical front face would be hidden behind the disc from the
default camera. That sign was wrong: the seeds appeared embedded in the disc
plane in side-view because the offset direction was the back-face normal.

**Root-cause fix.** Use the pool as ground truth. By construction, pool
seeds are below the disc on the front side — that's the whole point of
vacuum pickup. Define

```
disc_plane_eq(x, y, z) = -sin45°·y + cos45°·z
```

A pool seed at, e.g., (0, -29.7, -33) gives `disc_plane_eq = -2.33 < 0` →
front side. So FRONT_NORMAL is the unit vector pointing in the direction
of decreasing disc_plane_eq:

```
FRONT_NORMAL = -∇(disc_plane_eq) = (0, +sin45°, -cos45°) ≈ (0, +0.707, -0.707)
```

This is the SAME direction the SCAD afstrijkers were already mounted at —
validation showed afstrijker centroid at θ=250° offset from rim by
`h·(0, +sin45°, -cos45°)`. So the SCAD was right; only the viewer had the
wrong sign. Fixed: `FRONT_NORMAL` replaces `DISC_FRONT_VIS`, attached seeds
offset 5 mm in this direction.

Verification baked into the viewer:
- At startup, the topmost pool seed's `disc_plane_eq` is logged. Expected
  to be ≤ 0 (front side).
- At first pickup, the hole's and the attached seed's `disc_plane_eq` are
  logged. Expected: `seed < hole` (seed sits on front side, hole on plane).
- Sanity-check independently confirmed for θ ∈ {270°, 250°, 95°, 90°}:
  hole_eq = 0, seed_eq = −5 in all four cases.

After this fix, attached seeds at θ=270° land at world (0, -26.16, -33.23) —
inside the pool volume, sitting on the disc front face. At θ=90° they land
at (0, +33.23, +26.16) — directly above the geleider catch-mouth (mouth
y∈[20,40], z=20 to z=22), so the seed enters the catch zone naturally as
gravity pulls it down.

## Phase 4 V5 — Vacuum chamber + 4 mm holes + corrected seed mechanics (2026-04-27)

This phase is the LAST visual fix before STL export and PLA proof-of-concept
print. Three bundled changes:

**Change 1 — Pickup hole Ø 2.5 mm → Ø 4.0 mm.**
Soybean Ø ≈ 6 mm. The original 2.5 mm was a design holdover; the seed
only needs to seat against the disc-front around the hole, not pass
through. Increased to 4.0 mm: still strictly less than the seed diameter
(seed cannot escape forward through the hole), but with 60% more open
suction area per hole — better grip, more forgiving alignment. Updated
parameter `PICKUP_HOLE_DIA = 4.0` with comment locking the rationale.
Re-exported `disc.stl` (5928 vertices, volume 39 308 mm³).

**Change 2 — Attached-seed offset = SEED_RADIUS, not 5 mm.**
The previous viewer offset was 5 mm — picked when the conceptual model
was "seed centroid sits 5 mm in front of the hole". The physical model
is different: the seed-bottom *touches* the disc-front face, centred on
the hole. So the centre-to-disc offset is exactly SEED_RADIUS = 3 mm.
Changed `SEED_OFFSET = 5` (removed) → `FRONT_NORMAL.* * SEED_RADIUS` in
the three coordinate updates. Visually: attached seed now sits flush
against the disc; cross-section confirms seed-bottom on disc plane.

**Change 3 — Vacuum chamber on disc-back face.**
The missing structural element. Without a chamber, the vacuum has no
enclosure; pickup-holes inside the chamber sector experience suction,
holes outside it do not. The chamber is an annular sector hollow shell:

- Radii: `R_in = 30`, `R_out = 50` (pickup-hole circle R=42 sits inside).
- Depth: 8 mm along disc-back-normal (pre-tilt +Z).
- Sector: disc-local θ ∈ [90°, 270°] going through θ=180°, i.e. the
  half-plane `x_local ≤ 0`.
- Wall thickness: 2 mm; back plate, two end-walls, inner & outer
  cylinder walls. Open against the disc-back face (the disc itself
  forms the front cover — implicit O-ring grooves at R=30 and R=50).
- Hose nipple Ø 12 × 30 mm at the centre of the arc (θ=180°, R=40),
  pointing along disc-back-normal. After the SCAD `rotate([45,0,0])`,
  the nipple's far end ends up around world (-40, -25.5, +25.5).

New SCAD file: `scad/v5_4_vacuum_chamber.scad`. New parameters block in
`parameters.scad`: `VAC_CHAMBER_R_IN/R_OUT/DEPTH/WALL`,
`VAC_NIPPLE_DIA/LENGTH`, `VAC_SECTOR_START_DEG/END_DEG`. Exported
`stl/v5_4/vacuum_chamber.stl`: 392 vertices, 780 faces, watertight.

**Validation.** New `check_vacuum_chamber()` in `geometry_check.py` —
all PASS:
- `file_exists`: 392 vertices, 780 faces.
- `watertight`: True.
- `sector_x_range`: x ∈ [−50, 0] (chamber occupies the back-arc only).
- `centroid_on_back_side`: (−26.67, −6.67, +6.67) — x<<0 confirms sector,
  y<0, z>0 confirm the chamber is behind the tilted disc.

**Viewer integration.**
- New `vacuumChamberMat` material: blue-grey, opacity 0.30 — semi-
  transparent so attached seeds remain visible behind the chamber walls.
- Loaded via STLLoader; UI toggle "Vacuum-kamer (transparant)" controls
  visibility. Cross-section clipping plane added to the chamber material.
- Per-hole vacuum-glow markers: 40 small additive-blended blue spheres,
  one per pickup hole. Each frame, marker visibility = (vacuum > 5 AND
  hole's world x ≤ 0). Visualises which holes are *currently* in the
  chamber sector and active. UI toggle "Vacuum-glow" controls the glow.
- Vacuum-off behaviour: with the slider at 0%, every attached seed is
  immediately detached to falling at zero tangential velocity (drops
  straight down, almost certainly missed). At 5%-100% pickup proceeds
  normally — the binary cutoff at 5% is arbitrary, just there to model
  "vacuum on / vacuum off" without a smooth retention curve.

**Re-validation.** All component checks PASS, including the new chamber
checks. The pre-existing `disc_above_floor` D6 regression is unchanged
in nature (now reads −10.45 mm with the 4 mm-hole disc; was −10.82 mm
before). Decision still pending: lower pool floor to z = −50 OR strip
teeth until Phase 6.

**Tag:** v5.4. Phase 4 closes the V5 functional viewer. Next:
print preparation — production STL export, PLA proof-of-concept print
(disc + pool + afstrijkers + geleider + drop-tube + vacuum chamber).

## V5 anchor-based verification (2026-04-27)

Replaced abstract coordinate reasoning with anchor-based positioning. The
afstrijkers physically must be on the seed-side of the disc — that's their
job. They are therefore the visual ground truth. Once afstrijker positions
are derived from FRONT_NORMAL and confirmed visible on the pool side, all
other front-side components (attached seeds, geleider mouth) are positioned
along the same FRONT_NORMAL; the back-side component (vacuum chamber +
hose nipple) is positioned along -FRONT_NORMAL.

**FRONT_NORMAL (unchanged)**: `(0, +sin45°, -cos45°) ≈ (0, +0.707, -0.707)`.

**Anchor logging in viewer.js.** Added `logAnchorReport()` that runs at
startup and prints expected centroids for: afstrijker1 (θ=250°),
afstrijker2 (θ=95°), seed at pickup (θ=270°), geleider mouth, and chamber.
For each anchor it logs the same-Y-sign test (does it match the pool /
release reference?) plus the sign of disc_plane_eq (negative = front,
positive = back). On STL load, every loaded mesh's centroid is compared
to the computed anchor — afstrijker1 / afstrijker2 / chamber via
Euclidean distance with tolerance, geleider via sign-of-eq alone (its
curved hull spreads its centroid).

**Three-view rendered confirmation** (renders/v5_4_anchor/):

- `iso.png` — familiar iso-view; chamber annular ring + hose nipple
  visible behind disc, pool box at bottom in front of disc, drop-tube
  through centre, red/orange θ markers at rim bottom and top.
- `side_x.png` — camera at +X; disc appears as tilted blue stripe
  diagonal across frame; pool box at lower-left (front-side of disc
  plane line), chamber back-block + nipple cylinder at upper-right
  (back-side of disc plane line). Disc plane visibly separates the
  two halves.
- `front.png` — camera at -Y; disc seen full-face with 60 teeth.
  Pool box at bottom in front of the disc. Chamber barely visible as
  a translucent ring silhouette behind the upper half of the disc;
  hose nipple peeks out top-left. Matches the spec ("chamber should
  be HIDDEN behind disc or barely visible as silhouette").

**Acceptance criteria — all met**:

- [x] Both afstrijkers on the pool-side of disc (afstrijker1 at θ=250°
  with y=-22.96 same-sign as pool y_center=-30; afstrijker2 at θ=95°
  with y=33.83 same-sign as release y=+29.7)
- [x] Attached seeds on pool-side (seed at pickup: y=-27.6, z=-31.8;
  inside pool footprint, on front side of disc plane)
- [x] Geleider catch-mouth on pool-side (mouth y_center=+30, z=20;
  disc_plane_eq=-7.07 < 0, front side)
- [x] Vacuum chamber on opposite side (chamber centroid (-26.67, -6.67,
  +6.67); disc_plane_eq=+9.43 > 0, back side)
- [x] Side-view + front-view PNGs visually confirm the separation
- [x] Console log emits FRONT_NORMAL value and per-anchor verification
  on every viewer load

No SCAD changes; all geometry already at correct positions from prior
phases. This is a documentation/verification step that closes the
"which-side-is-front" thread for good. Skipping rubber-seal work as
per spec — that's a separate prompt.

## V5 FLIP — seeds and chamber side-swap (2026-04-27)

Hendrik observed in the viewer: "Seeds should be on the OTHER side of the
plate, and on that same side all the seeds in the reservoir. The vacuum
chamber should be placed BEHIND instead!" — i.e. the camera-visible side
(operator side) must show pool + attached seeds + afstrijkers, with the
vacuum chamber + nipple hidden behind the disc.

The previous anchor verification correctly proved the disc plane separated
the two halves, but the assignment of which-side-is-which had the chamber
on the operator-visible side. This entry inverts that.

**Sign flip**:

- `FRONT_NORMAL` was `(0, +sin45°, −cos45°) ≈ (0, +0.707, −0.707)`.
- Now `FRONT_NORMAL = (0, −sin45°, +cos45°) ≈ (0, −0.707, +0.707)` —
  points toward the default camera at (−Y, +Z).

**SCAD changes**:

- `scad/v5_4_vacuum_chamber.scad` — `vacuum_chamber()` now wraps
  `vacuum_chamber_pretilt()` in `mirror([0,0,1])` before the disc-tilt
  rotate. Chamber moves from +Z pre-tilt to −Z pre-tilt; after the
  rotate it sits behind the disc (operator's far side).
- `scad/v5_3_barriere_geleider.scad` — `afstrijker()` and `afstrijker2()`
  had their `mirror([0,0,1])` removed. Blades stay on the +Z pre-tilt
  face; after the rotate they end up on the operator-visible side
  (same side as the new attached seeds, where they physically must be
  to function as singulators).

**STL re-exports** (centroids):

- `vacuum_chamber.stl`: was (−26.67, −6.67, +6.67) → now
  (−26.67, +6.67, −6.67); disc_plane_eq = −9.43 (chamber side).
- `afstrijker.stl`: was (−14.36, −22.96, −32.86) → now
  (−14.36, −32.86, −22.96); seed side (eq ≈ +7.07).
- `afstrijker2.stl`: was (−3.66, +33.83, +25.34) → now
  (−3.66, +25.34, +33.83); seed side (eq ≈ +6.06).

**Validation** (`validation/geometry_check.py`): chamber centroid check
relabelled `centroid_on_chamber_side` (asserts cy>0, cz<0, eq<0);
afstrijker centroid checks switched to the flipped FRONT_NORMAL and
relabelled `_on_seed_side`. All Phase-3/4 checks PASS post-flip.
Pre-existing D6 `disc_above_floor` regression unchanged.

**Viewer changes** (`viewer/viewer.js`):

- `FRONT_NORMAL` flipped to `(0, −SIN_T, +COS_T)`; comment block
  rewritten for the operator-visible-side rationale.
- `ANCHOR.chamber` expected centroid updated to (−26.67, +6.67, −6.67).
- `placePoolSeed()` rewritten to constrain every reservoir sphere to
  the eq>0 (seed-side) half-space: pick layer-z first, clamp y so
  that `y < z − 1.5`. Result is a wedge of seeds piling against the
  far-y end of the pool, all on the camera-visible side of the disc
  plane.

**Three-view rendered confirmation** (renders/v5_4_anchor/, overwritten):

- `iso.png` — chamber + nipple barely visible behind upper disc edge;
  afstrijkers + pool + drop-tube visible in front of disc.
- `side_x.png` — disc as tilted blue stripe; pool box at lower-left
  (front side), chamber back-block + nipple cylinder at upper-right
  (back side). Plane separates the two halves with the new assignment.
- `front.png` — face-on view: afstrijker 2 visible at top of disc, pool
  transparent in front, chamber/nipple completely hidden behind disc.
  Textbook "pump from behind, seed from front" configuration.

**Tag**: v5.4.2.

---

## V5 polish — vacuum-respecting release glide + front-face tube ports (2026-04-27)

Three issues addressed in one pass:

**1. Seed-fall through disc at θ=90° release.** Old behaviour at top
release fell vertically from rim, visually clipping the disc plate
slab on the way down. With vacuum still on, seeds should ride the
disc face inboard until they clear the central hole, then drop. Added
a 2-stage glide in `viewer/viewer.js` (`glideToThroat`):

- Stage 1 (0.45 s): rim point (0, +29.7, +29.7) → disc-axis point
  (0, +2.12, +2.12), a slide along the disc FRONT face at constant
  disc-local-Z = +3 mm. Provably non-clipping: |Z|=3 > slab half-
  thickness 2, and once R<25 the disc has a central hole anyway.
- Stage 2 (0.30 s): central-axis point → geleider throat top
  (0, 0, throatZ+1). Linear drop down the central hole.

`pushToGliding()` now delegates to `glideToThroat()`. `updateGliding()`
handles `stage` field for two-stage entries (smoothstep on stage 1,
linear on stage 2). At-top release in animate loop replaces the
previous `detachToFalling` call with `glideToThroat(state.seed)`.

**2. Darker, less transparent shell materials** (`viewer/viewer.js`):

| Material | Old colour / opacity | New colour / opacity |
|---|---|---|
| `poolMat` | grey-blue 0x6a7886 / 0.45 | charcoal 0x3c4248 / 0.62  |
| `afstrijkerMat`  | warm grey 0x9ea4ad / 0.85 | dark grey 0x484c54 / 0.92 |
| `geleiderMat` | lighter grey 0x4d5560/0.55  | near-black 0x2c3036/0.72  |
| `dropTubeMat` | lighter grey 0x4d5560/0.65  | near-black 0x2c3036/0.82  |
| `vacuumChamberMat`| blue-grey 0x4d6075 / 0.45  | deep slate 0x232b34/0.62  |

Specular bumped to 0x111114 / 0x111118 across the board for a slight
sheen on the darker tone.

**3. Feeder + vacuum-cleanup tube ports on operator-facing front face.**
New parameters in `scad/lib/parameters.scad`:

- Feeder tube: OD 16, ID 12, length 50, 60° elevation, anchored at
  (x=+15, y=front, z=−22).
- Vac-cleanup tube: OD 32, ID 28, length 50, 45° elevation, anchored
  at (x=−15, y=front, z=−22).

Both modelled as cylinders along +Z then `rotate([90 - elev_deg, 0, 0])`
to tilt outward (-Y, +Z). Outer overlaps the wall; bore extends 5 mm
further inboard to fully pierce. New modules in `scad/v5_2_seed_pool.scad`:
`front_tube_outer/bore`, `feeder_tube_outer/bore`, `vac_clean_tube_outer/bore`.
`seed_pool()` unions tube outers, subtracts tube bores alongside the
existing pool cavity and disc envelope.

**STL re-export** (`stl/v5_3/seed_pool.stl`): 32v/60f → 865v/1742f;
copied to `viewer/models/seed_pool.stl`.

**Validation** (`validation/geometry_check.py`): Phase-2 pool checks
rewritten for tube extents:

- `x_extent_with_tubes`: 60.0 ±2.5 (vac tube nudges by ~1 mm)
- `z_floor`: exact at z = −37 (floor unaffected by tubes)
- `z_top_or_higher`: z_max ≥ −17 (tubes extend higher in +Z)
- `y_back_face`: exact at y = −10 (back wall unaffected)
- `y_front_or_further`: y_min ≤ −50 (tubes extend in −Y)

All five PASS at actual values (61.00, −37.00, 25.30, −10.00, −96.67).
Pre-existing `disc_above_floor` failure unchanged (teeth at z=−47.76
clipped by `disc_envelope_above_floor` half-space cut at z = floor+1).

**Tag**: v5.4.3.

---

## V5.5.0 — wider feeder + vac tube relocated to top, near-vertical (2026-04-27)

Stage A of Hendrik's Phase-5 spec. Stage B (half-circle recovery bowl
that wraps the disc 180° front-side) is deferred to v5.5.1 pending
review of this stage.

**Feeder tube — widened.** OD 16→18, ID 12→14. Bigger bore reduces
bridging risk for soybeans (Ø~6 mm). Same anchor (15, −50, −22),
same 60° elevation. Outer extent unchanged in X (still within +30
wall), nudges further in −Y/−Z (heavier tilt-cone footprint).

**Vac-cleanup tube — relocated.** Was: front-mount at (−15, −50, −22),
45° elevation, OD32/ID28. Hendrik's revised intent: vacuum mouth
"basically nearly inside the hopper" so suction lifts pool seeds
straight up, not pulling them sideways through a wall. Now:

- Anchor: mouth INSIDE pool at (0, −42, −30) — 7 mm above floor, on
  seed-side of disc plane (eq=+8.5 mm clearance from disc body slab).
- Elevation: 80° from horizontal (10° off vertical).
- Tilt direction: −Y from vertical → upper end is on operator side,
  hose attach reachable without fouling disc upper-half.
- OD/ID: 26/22 (matches standard Ø22 shop-vac hose + 2 mm wall).
- Length: 25 mm inside pool (mouth → top wall pierce) + 60 mm outside
  (hose attach span).

New `vac_clean_tube_outer/bore` modules in `scad/v5_2_seed_pool.scad`
no longer use `front_tube_*` helpers — they place the cylinder at
the mouth and rotate the whole thing by `90 - elev` (= 10°) about X.

**STL re-export** (`stl/v5_2/seed_pool.stl`): 865v/1742f → 899v/1810f.
Bounds: x[−30, +30] (was [−31, +30]); y[−82.79, −10] (was [−96.67,
−10]); z[−37, +55.97] (was [−37, +25.30]). Watertight. Copied to
`viewer/models/`.

**Validation** (`validation/geometry_check.py`): tightened
`x_extent_with_tubes` tolerance from ±2.5 to ±1.0 (vac tube no
longer pushes x_min past −30). Other four pool checks unchanged.
All five PASS at (60.00, −37.00, 55.97, −10.00, −82.79).
Pre-existing `disc_above_floor` failure unchanged.

**Cache-bust** in `viewer/viewer.js` (`?v=Date.now()` per page load)
ensures STL refetch on every page open — diagnostic console.log
prints loaded bounds for verification against the validation output.

**Tag**: v5.5.0.

---

## V5.5.1 — V-cone in both X & Y, floor lowered to clear disc teeth (2026-04-27)

Stage B-prep of Hendrik's Phase-5 spec — narrows the bowl into a true
V-cone in both dimensions and resolves the long-standing
`disc_above_floor` validation failure. The half-circle wraparound bowl
itself is still deferred to v5.5.2.

**Floor lowered.** `SEED_POOL_DEPTH` 20→33; floor moves from
z=−37 → z=−50. Reason: disc-with-teeth lowest world Z at α=270° is
−47.76 mm (back-face teeth). Old floor at −37 sat 10.76 mm ABOVE the
teeth, requiring `disc_envelope_above_floor` to clip the disc-cut
half-space (otherwise teeth carved a slot through the floor). New
floor sits 2.24 mm BELOW the teeth → disc clears the floor in the
mesh and the validation check passes without the half-space hack.
The half-space clip is kept defensively (cheap insurance against
future teeth-OD growth).

**V-cone in Y.** Added `SEED_POOL_BOTTOM_Y = 4` (was implicitly =
inner_y = 36 — the bottom strip was a long ridge, not a cone). Now
the cavity is a true 4×4 mm bottom widening to 56×36 at the top.
Wall slopes:
- X-wall: atan((28−2)/33) = 38.2° (was 36.9°) — still ≥35°.
- Y-wall: atan((18−2)/33) = 25.9° in body, but bottom strip narrows
  Y to 4 → effective floor-up Y slope atan((36−4)/2 / 31) = 27.3°.
  This is BELOW the ≥35° spec target. Workable for soybeans (low
  rest angle) but flagged for v5.5.2 review — likely fix is
  narrowing top Y or further lowering bottom_y.
- `SEED_POOL_BOTTOM_X` 6→4 (matches BOTTOM_Y; tighter pickup lane).

**STL re-export**: 899v/1810f → 985v/1982f. Bounds: x[−30,+30]
unchanged; y[−82.79,−10] unchanged; z[−50, +55.97] (floor moved
−13). Watertight. Copied to `viewer/models/`.

**Validation**: `disc_above_floor` now PASSES — no disc surface
samples within 1 mm of pool floor (z=−50). All other six checks
PASS at (60.00, −50.00, 55.97, −10.00, −82.79). Updated
`SEED_POOL_DEPTH=33` and `SEED_POOL_Z_FLOOR=−50` constants in
`validation/geometry_check.py`.

**Iso render**: `renders/v5_2/v5_5_1_iso.png` shows narrower V-cone
profile through the front wall.

**Tag**: v5.5.1.

---

## V5.5.2 — half-disc footprint pool, wraps disc bottom 180° (2026-04-27)

Stage B of Hendrik's Phase-5 spec: the rectangular 60×40 pool becomes a
half-disc (radius 55, opening at y=0, footprint y ≤ 0). Wraps the disc
bottom 180° in plan view — any seed detaching mid-travel whose XY
projection lands in the half-disc footprint is now caught by the pool.

**Footprint change.** Body geometry switched from
`cube([60, 40, 33])` to `difference(){ cylinder(r=55,h=33); cube(y>0 half) }`.
Cavity follows the same pattern: hull from a half-disc of radius
R_INNER=53 (top opening) down to the existing 4×4 mm V-cone patch at
(0, -30, floor+2). Floor still z=-50, top still z=-17.

**Why R=55.** Sized to keep the existing tube anchors INSIDE the body:
- feeder anchor (15, -50, -22): radius √(15² + 50²) = 52.2 < 55 ✓
- vac    anchor (0, -42, -43): radius 42 < 55 ✓
Both tubes still emerge through the pool wall (now curved instead of
flat) — the tube body's back end overlaps the wall by SEED_POOL_WALL+EPS,
union stays watertight, bore pierces through to the cavity.

**Wall slopes.** With V-cone at (0, -30, -48) and half-disc top R=53:
- Front edge (toward -Y): bottom (0,-30,-48) → top (0,-53,-16). Slope
  atan(32/23) = **54°** ✓
- Back edge (toward +Y): bottom (0,-30,-48) → top (0,0,-16). Slope
  atan(32/30) = **47°** ✓
- Side edges (toward ±X): bottom (0,-30,-48) → top (±53,0,-16).
  Slope atan(32/√(53²+30²)) = **28°** ⚠ below ≥35° spec.

The shallow side slope is a known limitation of the half-disc shape
+ single-point V-cone. Soybeans (rest angle ~25-30°) will roll on
28° but it's tighter than ideal. Mitigations for v5.5.3+:
1. Replace single V-cone with a curved trough following the disc rim
   path projection — seeds drain along the disc-bottom arc.
2. Tighten R_OUTER to ~40 (gives ~38° side slopes) at the cost of
   smaller catch area.
3. Add a rim-following internal rib to break the long side slope.

**Disc-envelope subtraction unchanged.** The disc rim with teeth
crosses the half-cylinder pool wall at world-XY radius 55 at z=-36.5
(two crossings per side, at θ_disc=231°/309° on the bottom-half).
The clipped disc envelope (z ≥ floor+1) carves a slot through the
curved wall at these crossings — same mechanic as the rectangular
pool's left/right wall slots.

**STL**: 985v/1982f → 1143v/2294f. Bounds: x[−55, +55] (was [−30,+30]),
y[−82.79, 0] (was [−82.79, −10]), z[−50, +42.97] unchanged.
Watertight. Copied to `viewer/models/`.

**Validation**: replaced `y_back_face` check (was y_max≈-10) with
`y_back_edge` (y_max≈0, the half-disc opening). Updated
`x_extent_with_tubes` to 2·R_OUTER=110 and `y_front_or_further` to
≤ -R_OUTER=-55. All seven pool/clearance checks PASS at
(110.00, −50.00, 42.97, 0.00, −82.79).

**Iso render**: `renders/v5_2/v5_5_2_iso.png`.

**Deferred to v5.5.3+** (per Hendrik's full Phase-5 spec):
- Drainage rib / curved bottom trough for ≥35° slopes everywhere
- "Clean cycle" UI button + vacuum-suction animation
- Seed-loss tracking visualisation (prove zero seed loss between lines)

**Tag**: v5.5.2.

## V5.6.0 — Phase 5: top-half recovery bowl + clean-cycle animation (2026-04-28)

Closes Phase 5 of the build plan. Two new pieces and a batch of audit
cleanups, all in one commit so the working tree stays coherent for the
backup tag.

**5a — Top-half recovery bowl (`scad/v5_5_recovery_bowl.scad`).**
Half-disc shell, footprint y ≥ 0, R_OUTER=55, z ∈ [22, 50]. Mirrors the
bottom-pool footprint (D10) on the y ≥ 0 side for visual symmetry.
Floor at z=22 sits flush on the geleider top; a 40×20 mm rectangular
drain in the floor (centred on y=30) opens directly into the geleider
catch-mouth. Disc-envelope subtraction (3 mm clearance) carves a slot
where the disc rim crosses the bowl outer wall (at world (±41.2, 36.5,
36.5)) — same approach as D6/D7. STL: 286 v / 572 f, watertight,
bounds x[−55,+55] y[0,55] z[22,50]. All seven Phase-5 validation checks
PASS, including disc-clearance at min=2.92 mm vs nominal 3.0 (the
0.08 mm gap is the chord-error of $fn=64 at R=66; tolerance set to
0.15 mm in the validator).

**5b — Self-cleaning vacuum cycle (viewer-only).** New "Start clean
cycle" button in the controls panel. While active:
- Vacuum is forced to 0 internally (the existing vacuum<5 path detaches
  every attached seed back into the falling pile).
- Pool refill is suppressed — the compartment is allowed to empty.
- Pool seeds are pulled into the top-mount vac-cleanup tube at
  CLEAN_RATE = 3 seeds/s. Each suck is a two-stage glide animation:
  pool position → tube mouth (0, −42, −43), 0.40 s eased; then mouth →
  tube end (0, −56.4, +40.7), 0.50 s linear. Seed counts toward a new
  cumulative `Cleaned` HUD field.
- Toggling off resumes normal seeding (refill kicks back in, vacuum
  follows the slider).

**Audit cleanups bundled in same commit:**
- `viewer/viewer.js` `POOL` block updated to half-disc geometry
  (rOuter=55, depth=33, zFloor=−50). `placePoolSeed()` rewritten to
  spawn within the half-disc footprint with chord-bound x range.
- `stl/v4_2/{disc,reservoir}.stl` deleted (V4 reservoir architecture
  retired in commit 8f1f881; the orphan STLs had no SCAD source).
- `docs/decisions.md` D8 (FLIP), D9 (vacuum-respecting glide), D10
  (half-disc footprint) backfilled — all three were documented in the
  build log but never promoted to numbered decisions.

**Validation**: `python3 validation/geometry_check.py` — all 36 checks
PASS (Phase 1 disc + Phase 2 V5 pool + clearance + Phase 3 afstrijkers
+ geleider + drop-tube + Phase 4 chamber + Phase 5 bowl).

**Browser verification**: not performed in this build environment (no
display). The viewer code paths are coherent (anchor-verify block
gates every STL load with PASS/FAIL log) but the clean-cycle animation
and the recovery-bowl rendering still need a human eyeball before
Phase 6.

**Iso render**: `renders/v5_5/v5_5_iso.png`.

**Tag**: v5.6.0. Also tagging `phase5-backup` per Hendrik's request as
the rollback point before Phase 6 (gear drive + motor mount) starts.

## V5.6.1 — Vacuum chamber 1 mm air gap (2026-04-28)

Resolves the chamber-air-gap question flagged in the second audit. The
Phase-4 spec mentioned 1.5 mm; the existing model used 0.01 mm (an
EPS sliver, effectively zero). Hendrik chose 1 mm — middle of the
real-machine range (Monosem/MaterMacc typical 0.5–1 mm with PTFE wiper),
small enough to keep vacuum loss across the seal manageable.

**Implementation.** New `VAC_CHAMBER_AIR_GAP = 1.0` in
`parameters.scad`. In `v5_4_vacuum_chamber.scad`, the chamber-front
translate changed from `DISC_THICKNESS / 2 - EPS` to
`DISC_THICKNESS / 2 + VAC_CHAMBER_AIR_GAP`, pushing the entire chamber
1.01 mm farther from the disc back face (post-mirror+tilt → 1 mm gap
on the operator-far side). Cavity inset logic unchanged.

**Geometric impact.** Chamber STL 392v/780f, watertight, sector-x range
[−50, 0] unchanged. Centroid shifted from (−26.67, +6.67, −6.67) to
(−26.67, +7.38, −7.38) — exactly +0.71/−0.71 along the disc-back-normal
(0, +sin45°, −cos45°), which equals 1 mm × sin/cos 45° as predicted.
`disc_plane_eq` = −10.44 (was −9.43); still well clear of the seed-side
half-space.

**Anchor update.** `viewer.js` `ANCHOR.chamber` updated to the new
expected centroid; the on-load anchor verification keeps PASSing within
its 2.0 mm tolerance.

**Validation**: 36/36 PASS.

**Tag**: v5.6.1.

## V5.7.0 — Phase 6: integrated disc-mal element (2026-04-28)

Major architectural shift per Hendrik's Phase-6 spec: consolidate the
standalone Phase-4 vacuum chamber and parts of Phase 5 into a single
3D-printable plate ("mal-plate") that holds the disc, drives it, and
provides vacuum suction.

**Architectural changes (D11, D12):**
- Mal-plate is now the central structural element. Standalone Phase-4
  vacuum chamber retired (archived in `scad/archive/`).
- Phase 5 (recovery bowl, clean-cycle) discarded per Hendrik's option
  (c). Will be rebuilt around the mal-plate. Recovery bowl SCAD/STL
  archived; clean-cycle UI button kept (UI-only, no geometry tie).
- Phase 7 (edge-roller bearings) retired. Disc floats in the plate
  recess with 0.5 mm front + back clearance and an O-ring providing
  rear retention.

**Mal-plate geometry (`scad/v5_6_disc_mal.scad`):**
- Body 180 × 180 × 15 mm tilted 45° around world-X.
- Disc-recess Ø 134 × 5 mm deep on plate-front; disc sits with 0.5 mm
  clearance front and back.
- Vacuum chamber as cavity inside plate: 180° sector R=32..52, depth 8,
  back wall 2 mm. Centred on R=42 pickup circle (Phase 4 was R=30..50,
  off-centre; new range gives 10 mm margin each side).
- O-ring groove on recess-back-wall: ISO-3601 face-seal for 2.5 mm NBR
  cord, 3.2 wide × 1.9 deep. Path follows chamber perimeter (outer arc
  R=53, inner R=31, end straights at θ=90°/270°).
- Motor cut-out 36 × 36 mm at θ=180°, plate-through. Pinion centre at
  world (-75, 0, 0). Shaft bore Ø 7 (5 mm shaft + 1 mm clearance × 2).
- Hose nipple Ø 12 OD / Ø 8 ID × 30 mm long on plate-back at chamber
  midpoint (-42, 0).

**Drive (visual model, not for FEA):**
- 20T pinion at module 1.5 (OD ≈ 33). Trapezoidal teeth matching the
  disc's trapezoid scheme. Pitch radius 15, centre at X=-75.
- NEMA17 stepper body modelled as a 42 × 42 × 47 mm box behind the
  plate-back face. Animation rotates pinion at 3× disc rate (60T/20T)
  in opposite direction (external mesh).
- Per spec note: TMC2208 driver for silent operation (€8); total motor
  + driver ≈ €25–30 from Aliexpress. Driver electronics not modelled.

**STL stats** (all watertight):
- mal_plate: 705 v / 1410 f, bounds x[-90,+90] y[-65,+72] z[-72,+65]
  (post-tilt); centroid (0.12, +4.67, -4.67), eq=-6.61 → disc-back side.
- pinion: 424 v / 848 f, centroid (-75.00, 0.00, 0.00) on disc axis.
- motor: 8 v / 12 f (axis-aligned box), centroid (-75, +25.46, -25.46).

**Validation**: 35/35 PASS. New checks: disc_mal x_extent, y_extent,
z_extent, centroid_on_back_side, disc_clearance; pinion centre_x_at_-75,
centre_yz_near_axis, x_extent.

**Viewer changes:**
- Removed `vacuum_chamber.stl` and `recovery_bowl.stl` loads; removed
  `Vacuum-kamer` and `Recovery bowl` toggles.
- Added `mal_plate.stl`, `pinion.stl`, `motor.stl` loads with new
  toggles. Added pinion rotation in the animation loop at +3× disc
  rate (opposite direction).
- ANCHOR.chamber removed (chamber is no longer a separate STL).
- Title and section header updated to "Phase 6 (integrated disc-mal
  element)".

**Iso render**: `renders/v5_6/v5_6_iso.png`.

**Open items / deferred:**
- Phase 5 components (bowl, feeder/vac-cleanup tubes, clean cycle) need
  to be rebuilt with M3 attachment points to the mal-plate.
- Real involute pinion sized to disc's actual trapezoid teeth (effective
  module ~2 vs spec module 1.5) — fix when ordering / printing the real
  drive train.
- Disc retention long-term: PTFE radial insert vs slop in plain recess.
  Decide after first physical print.
- Browser eyeball verification of pinion rotation, mal-plate cross-
  section view, and chamber visual.

**Tag**: v5.7.0.

## V5.8.0 — Phase 7: integrated transparent housing (2026-04-28)

Phase 7 spec from Hendrik. Replaces the half-disc seed pool with a
proper funnel-shaped hopper, integrates the feeder + vac-cleanup tubes
as channels through the housing wall (only short connector stubs
protrude), and adds a transparent protective lid with a rubber dust-
seal ring at the disc-OD radius.

**Hopper geometry** (`scad/v5_7_housing.scad`, world coords, axis vertical):
- Wide top 100 × 80 mm at world z=+33 (operator pours seeds in here)
- Narrow bottom 30 × 30 mm at world z=-47 (just at disc-rim level so
  the disc-rim at θ=270° dips into the pool surface)
- Pool reservoir extends 20 mm down to z=-67 (closed floor)
- Wall thickness 2 mm; built as `hull(top_box, bottom_box) ∪ pool_box`
  with cavity inset by 2 mm on every face
- Total height 100 mm (80 funnel + 20 pool)

**Integrated tubes** (rendered as connector stubs with bore through wall):
- Feeder: connector ID 14 mm, length 25 mm, 60° elevation, mounted on
  hopper-front-face (y=-86.67) at x=+15
- Vac-cleanup: connector ID 22 mm, length 30 mm, 80° elevation
  (10° off vertical), mounted on hopper-top-face

**Protective lid** (separate STL, tilted 45° with disc):
- Ø 144 × 4 mm thick, sits 8 mm in front of disc-front face
- Cutouts: pickup-zone window (40×25, θ=270° area), release-zone
  window (40×25, θ=90° area, sized for geleider catch-mouth), central
  hole Ø 54 for drop-tube
- 4× M3 mounting inserts deferred to next iteration (visualisation
  doesn't render the inserts)

**Rubber dust-seal ring** (separate STL):
- NBR-style ring, Ø 130 inner / Ø 144 outer × 3 mm thick
- Sits on lid-bottom-face at z = +3 (disc-local pre-tilt)
- Touches disc-OD-with-teeth (132) just inside ring inner Ø (130) →
  light interference for sealing
- Visible in viewer as dark red

**Drive gear "proportions" — verified** (per spec). Pinion is module
1.5 / 20T → OD ≈ 33 mm. Disc is spec'd at module 1.5 / 60T → pitch
Ø 90, OD ≈ 132 (with addendum). Visual ratio of pinion (33) to disc
tooth-tip-circle (132) is **1/4**. The "1/3" the spec mentions
applies to pitch-to-pitch ratio (30/90), not visual OD-to-OD.
Pinion is mathematically correct for the spec; what looked "small"
in screenshots is just the pitch-vs-tip discrepancy. Left as-is per
Hendrik's option (a). Documented in D11.

**Mal-plate disc-recess overlap** (pre-existing from Phase 6, surfaced
in Phase 7 conflict report). The mal-plate's Ø 134 disc-recess fully
encloses the disc rim. Phase 5 pool and Phase 7 hopper both need
disc-rim access at θ=270°. In the viewer the meshes just visually
overlap (no boolean intersection enforced); physical hardware would
need a θ=270° access cutout in the mal-plate. Left as a known issue
per Hendrik's option (b).

**Animation preservation.** Per the spec's emphatic warning: the seed
lifecycle code (`holeState`, `holeIsAt`, `holeWorldPosition`, all
`update*` functions, rotation calculations) was NOT touched. Only
`POOL` constants and `placePoolSeed()` bounds were updated to spawn
seeds in the new hopper-narrow-bottom geometry. Lifecycle anchors
verified intact (35 references to lifecycle symbols, all unchanged).

**File changes:**
- `scad/v5_2_seed_pool.scad` → `scad/archive/`
- `viewer/models/seed_pool.stl`, `stl/v5_2/seed_pool.stl` deleted
- New: `scad/v5_7_housing.scad`, `stl/v5_7/{hopper,lid,dust_ring}.stl`,
  `viewer/models/{hopper,lid,dust_ring}.stl`
- `parameters.scad` gained HOPPER_*, FEEDER_CHANNEL_*, VAC_CHANNEL_*,
  LID_*, DUST_RING_* params
- `validation/geometry_check.py`: retired `check_seed_pool` /
  `check_disc_floor_clearance`; added `check_hopper`, `check_lid`,
  `check_dust_ring`
- `viewer.js`: removed `poolMat` and `seed_pool.stl` load; added
  `hopperMat`, `lidMat`, `dustRingMat` and the three STL loaders;
  rewrote `placePoolSeed()` for the new 30×30 narrow bottom
  footprint; added 3 toggles + button listeners
- `viewer/index.html`: title bumped to "Phase 7"; added 3 toggles
- `viewer/styles.css` unchanged

**Validation**: 44/44 PASS. Hopper 782 v / 1568 f watertight; lid 272 v
/ 552 f watertight; dust-ring 256 v / 512 f watertight.

**Iso render**: `renders/v5_7/v5_7_iso.png`.

**Open items / deferred:**
- M3 mounting inserts in lid + plate not modelled.
- Mal-plate θ=270° access cutout (visual overlap only, see D13).
- Real housing-wall cast tube channels (current model has stub
  connectors; the "channel through the wall" is implicit).
- Feeder channel and vac-cleanup channel don't actually carve through
  the hopper wall as fluid paths — they're separate cylinders that
  bore through. For visualisation that's fine; for printing that
  would need a single `union` with proper wall thickness throughout.

**Tag**: v5.8.0. Backup tag: `phase6-pre-housing-backup` at v5.7.0.

## V5.8.1 — Wider/sounder lid + shallower pool (browser eyeball fixes)

Hendrik browser-eyeballed v5.8.0 and called out: "seed basket is far
below the plate", "inlet is out of the cover", "cover is very slim —
make it wider and sound, so seeds fall not below or behind the plate."

Three small parametric fixes (no structural redesign):

1. **Lid widened and thickened.** `LID_OD` 144 → 200 (covers entire
   plate width plus 10 mm bezel). `LID_THICKNESS` 4 → 6. Added a side
   rim (`LID_RIM_HEIGHT` = 15, `LID_RIM_THICKNESS` = 4) — a 4 mm thick
   annular cylinder extending 15 mm back from the lid-front-face,
   wrapping around the disc rim. Cutouts at θ=270° / θ=90° span both
   the front face and the side rim so the disc rim is exposed at the
   pickup and release zones; the central hole stays in the front face
   only. `LID_OFFSET_FROM_DISC` 8 → 12 to keep the now-thicker lid
   clear of the disc-front face. Lid STL bumped from 272v/552f to
   400v/808f, x-extent now 200 mm.
2. **Pool floor raised 6 mm.** `HOPPER_POOL_DEPTH` 20 → 14, so the
   pool floor moves from world Z=-67 to Z=-61. The plate's front-edge
   bottom in world is at Z≈-61.7 (plate-local Y=-90, Z=+2.5 after
   45° tilt), so pool seeds now sit just above that edge instead of
   ~6 mm below. Visually the pool no longer extends past the plate's
   front edge.
3. **Dust-ring OD decoupled from lid OD.** New `DUST_RING_OD` = 144
   (was implicitly = `LID_OD`). Ring stays sized to the disc-OD-with-
   teeth + 12 mm clearance for the rubber-seal interface; lid widening
   doesn't bloat the ring.

**Animation**: untouched (lifecycle code unchanged). `viewer.js`
`POOL.zFloor` constant updated from -67 to -61 to match the shallower
pool, otherwise no JS changes.

**Validation**: 44/44 PASS. Hopper bounds shrink Z=[-67,72.69] →
Z=[-61,72.69]. Lid bounds grow x=[-72,+72] → x=[-100,+100].

**Open items unchanged**: feeder still emerges from hopper-front-face
rather than from the lid (would need a more substantial redesign with
the feeder routed through the lid into the hopper from above — flagged
as future work). Mal-plate disc-recess overlap (D13) still accepted.

**Tag**: v5.8.1.

## V5.8.2 — Lid as annular ring; hopper at pickup zone

Browser eyeball v5.8.1: "top lid is way too large", "seed hopper should be
very close to seed pickup not close to the border of the disc", "cover
should cover outer 1-2 cm of the disc, so the teeth are not open, but
closed", "seeds should be in the hopper — hopper is now placed into the
air. This should be smoothly integrated in the lid."

Three changes (no animation lifecycle touches):

1. **Lid is now an ANNULAR RING.** OD shrunk 200 → 140 (covers disc
   teeth at R=66 plus 4 mm bezel), with new `LID_INNER_DIA = 112` (R=56)
   so the inner 56 mm radius of the disc — including the pickup-hole
   circle at R=42 and the central hole — stays open. Side rim removed.
   Cutouts at θ=270° (hopper access) and θ=90° (geleider release) are
   now narrow radial slots through the ring rather than full-thickness
   rectangles. Function: covers the outer disc body + teeth (so teeth
   aren't open), retains disc front, leaves the working area visible.

2. **Hopper repositioned to pickup zone.** `HOPPER_Y_CENTRE` moved
   from world Y=-46.67 (disc-rim plan) to Y=-30 (pickup-hole plan, R=42).
   Pool surface raised from z=-47 to z=-32 (just below disc-back face
   at the pickup point). Hopper shrunk significantly: top 100×80→50×35,
   bottom 30×30→22×22, height 80→25 mm, pool depth 14→10 mm. Pool
   floor at z=-42, well above the plate-front-edge at z=-61.7. Visually
   the hopper now sits right at the pickup zone instead of dangling
   below the disc rim.

3. **Vac-cleanup connector retired temporarily.** With the smaller
   hopper, the vac-stub anchor at (0, Y_CENTRE-5, TOP_Z) landed inside
   the open hopper-top cavity, breaking 2-manifoldness on STL export.
   Removed for now; can be re-added as a separate non-booleaned mesh
   if Hendrik wants the "integrated wall channel" visual back.

**Animation untouched.** `viewer.js` `POOL` constants updated parametrically
to match new spawn region (bottomX/Y=22, yCenter=-30, zFloor=-42,
fillZ=-34). Lifecycle code (`holeState`, `update*`, rotation calcs) all
unchanged.

**STL stats**:
- hopper 447 v / 898 f, watertight, bounds x[-25, +25] y[-68.8, -12.5]
  z[-42, +12.9] (feeder connector extends y to -68.8, z to +12.9)
- lid 240 v / 472 f, watertight, x[-70, +70] (OD 140)
- dust_ring 256 v / 512 f unchanged

**Validation**: 44/44 PASS.

**Open**: hopper-to-lid "smooth integration" is still visual proximity
only, not a boolean union — would require the lid's inner edge at θ=270°
to extend down to meet the hopper top, or the hopper to grow up into
the lid plane. Either way needs a more substantial SCAD redesign than a
parametric tweak. Flagged for future iteration.

**Tag**: v5.8.2.

## V5.8.3 — Closed lid ring; 100-seed fill across full hopper volume

Browser eyeball v5.8.2: "seed should stay in the hopper, not at the
bottom — bottom and upper cover ring closed — no bottom hole in hopper —
let 100 seeds enter the hopper, after 80 seeds 20 are sucked out by
vacuum."

Three changes (all parametric/visual; no lifecycle changes):

1. **Lid is a closed annular ring** (no cutouts). The pickup-zone and
   release-zone slots from v5.8.2 turned out to be unnecessary: in
   WORLD plan view the lid covers world Y ∈ [-42, -52] at θ=270° (disc
   teeth area) and Y ∈ [+42, +52] at θ=90°, but the pickup hole
   (world Y=-29.7) and the geleider mouth (world Y=+30) sit INSIDE the
   lid's inner ring (which opens at world plan R≈40). So the disc
   teeth are now fully covered by a closed ring; the working elements
   are not blocked. Lid STL bounds unchanged; vertex/face count steady.

2. **100 seeds in the hopper.** `POOL_TARGET` 50 → 100, `POOL_REFILL_AT`
   12 → 20. Cycle: hopper fills to 100, disc picks ~80 over time, when
   pool reaches 20 the auto-refill brings it back to 100. Matches
   Hendrik's "100 enter, 80 picked, 20 refilled" pattern.

3. **Seeds spread through the full hopper volume.** The previous
   `placePoolSeed()` capped seeds at `fillZ = -34` (just above pool
   surface), so 100 seeds piled densely on the 22×22 mm pool floor and
   were mostly hidden inside the hopper's narrow bottom. Now `fillZ =
   -10` (just below hopper top) and the spawn footprint expands with
   z to match the hopper's funnel cross-section: constant 22×22 mm in
   the pool zone (z ≤ -32), then linear interpolation up to 50×35 mm
   at hopper top (z = -7). Seeds now visibly fill the hopper.

**Hopper bottom is closed** — confirmed in v5_7_housing.scad by
inspection. The pool reservoir is a solid box from z=-42 to z=-31
(extra 1 mm overlap with the funnel hull above). Pool floor at z=-42
is solid material (`hopper_outer_solid()`'s pool-box minus
`hopper_cavity()`'s pool-cavity = wall thickness 2 mm at the floor).
No leak.

**Animation lifecycle**: untouched. Only the parametric `POOL` block,
spawn function, and target/refill constants changed.

**STL stats**: hopper unchanged from v5.8.2 (447v/898f). Lid 256v/512f
(was 240v/472f — the cutouts removed simplified the geometry slightly).

**Validation**: 44/44 PASS.

**Open** (carried over): hopper-to-lid is still visual proximity
only, not booleaned together. Vac-cleanup tube still retired (its
"sucks out 20" function from the spec is currently emulated by the
auto-refill bringing pool back to 100; could be re-added as a separate
animation if you want the visual).

**Tag**: v5.8.3.

## V5.8.4 — Vac-cleanup tube re-added; feeder seed-flow animation

Browser eyeball v5.8.3: "cleanout!" + "vacuum tube as large as feeder
tube" + "feeder tube should actually show seeds flowing into hopper" +
"be nicely integrated with hopper. So not hanging in the air".

Three changes:

1. **Vac-cleanup tube re-added as a standalone STL.** Mounted with
   mouth INSIDE the open hopper-top cavity at world (0, -35, -34) — 8 mm
   above pool floor, slightly toward operator from hopper centre. Tube
   extends 60 mm at 80° elevation (10° off vertical, tilting toward
   operator −Y) so the external connector at world (0, -45.4, +25.1)
   is reachable. Same OD/ID as the feeder per Hendrik (`VAC_TUBE_OD`
   = 18, `VAC_CHANNEL_ID` = 14). Standalone module — NOT booleaned
   with the hopper outer (which previously broke 2-manifoldness on
   small-hopper geometry). Watertight 256v/512f.

2. **Feeder seed-flow animation.** Refill no longer teleports seeds
   into the pool — they now drip in through the feeder tube at
   `FEED_RATE` = 4 seeds/sec. Each seed spawns at the feeder external
   tip (world (15, -60, +6.65)), animates 0.55 s eased lerp into a
   target pool position computed by the new
   `computePoolSpawnPosition(occupancyCount)`, then transitions into
   the regular `poolSeeds[]` array. State: `feedingSeeds[]`,
   `feedingGroup` THREE.Group, `refillRemaining` queue counter,
   `feedAccumulator`. `pumpFeeder(dt)` and `updateFeeding(dt)` hook
   into the animation loop.

3. **Clean-cycle suction now uses the actual vac-tube position.**
   `VAC_CLEAN_MOUTH` constant updated from the old (0, -42, -43) to
   the new tube mouth (0, -35, -34); `VAC_CLEAN_END` follows the
   60 mm tube length to (0, -45.4, +25.1). Clean cycle visually
   sucks pool seeds along the actual tube path now.

**Lifecycle preservation**: `placePoolSeed()` was refactored — the
position-computation logic moved into a pure helper
`computePoolSpawnPosition(occupancyCount)`, and `placePoolSeed()` now
just calls the helper. No change to the pickup / attached / falling /
gliding / exiting transitions or rotation calculations.

**Validation**: 47/47 PASS (added `check_vac_tube` for the new STL).

**STL stats**: hopper / lid / dust_ring unchanged from v5.8.3. New
vac_tube 256v/512f watertight.

**Open** (still): the feeder anchor at world (15, -47.5, -15) is at
the hopper-front-wall *top edge* in disc-local; at z=-15 the actual
front wall has crept inward to y≈-45.4 due to the funnel slope, so
the feeder cylinder body floats ~2 mm in front of the wall there.
Visually it's close enough that the boolean union still produces a
watertight STL, but for a "perfectly snapped to wall" look the anchor
would need to be computed from the wall-slope equation. Flagged for
future iteration.

**Tag**: v5.8.4.

## V5.8.5 — Round mal-plate + lid retention clips

Browser eyeball v5.8.4: "from the square black plate make it a nice 1 cm
rounding around the disc, maybe with clips to fix the upper cover. Should
look like a nice round seed element. Not a tile you place on the floor."

Two changes (re-touches `scad/v5_6_disc_mal.scad` despite the original
"DO NOT TOUCH mal-plate" rule, since this is an explicit redesign request):

1. **Plate is round now.** OD = 152 mm (disc-OD-with-teeth at 132 +
   2 × 10 mm radial margin). `MAL_PLATE_OD = 152` added to
   parameters.scad; old `MAL_PLATE_X` / `MAL_PLATE_Y` retained for
   validation back-compat (now both equal 152). Plate body changed
   from `cube([180, 180, 15])` to `cylinder(d=152, h=15)`. The motor
   cutout at θ=180° still carves a notch into the -X edge, so the
   plate's leftmost extent is at world X≈-73.7 (slightly less negative
   than the unfilleted -76 due to cutout subtraction).

2. **4 lid retention clips on plate-front.** Cylindrical posts at
   disc-local θ ∈ {45°, 135°, 225°, 315°} (between motor at 180° and
   hopper at 270° — clear of both). Each post: OD 10 × 14 mm tall,
   with a 3.2 mm bore for M3 screw clearance. Clip top at disc-local
   Z=+16.5, reaching past the lid front face (z=+10) by 6.5 mm so
   the screw can clamp the lid down. Posts at radial distance R=72
   (just outside the lid OD/2=70).

**Geometry sanity:**
- Plate STL grew from 705v/1410f to 1851v/3702f (curved cylinder body
  + 4 clip posts add geometric detail).
- Y/Z extents shrink from 137.89 → 118.09 (round plate's y/z =
  152·cos45° + 15·sin45° = 118.1).
- Centroid still on back side (eq=-6.79 < 0).

**Validation**: 47/47 PASS. Mal-plate `x_extent` tolerance widened
from 1 mm to 4 mm to accommodate the motor cutout's notch in the round
edge.

**Animation**: untouched.

**Open**: clips are simple cylindrical posts — for a more polished
look they could have a top "hook" tab that overhangs the lid edge for
a snap-fit retention. Current visual: posts pass through 4 small
notches in the lid (lid currently has no such notches — the posts
just extend past the lid OD=140 at R=72, so they sit just outside the
lid edge in plan view). For a real assembly the lid would need M3
clearance holes drilled at R=72 / θ ∈ clip angles; that's a 1-line
SCAD addition flagged for next iteration.

**Tag**: v5.8.5.

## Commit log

2026-04-27 Phase 1: parametric disc + viewer bootstrap
    - scad/lib/parameters.scad with all V4 dimensions
    - scad/lib/helpers.scad: cross-section + material modules
    - scad/v4_1_disc.scad: 120/132 mm disc, 4 mm thick, 50 mm central hole,
    40 pickup holes (Ø2.5 on R=42, perpendicular to disc plane), 60
    trapezoidal teeth, tilted 45° around world X
    - validation/geometry_check.py: watertight + bbox + volume + centroid checks
    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
    [disc.stl, v4_1_disc.scad]
2026-04-27 Phase 2: spits reservoir + seed-fall animation
    - scad/lib/parameters.scad: PICKUP_TOP_POS, DISC_TOP_Z_OFFSET, reservoir
    block with RESERVOIR_OUTLET_CLEARANCE=17 mm (was 14, see D4)
    - scad/v4_2_reservoir.scad: hull-based funnel from 60x60 top to Ø16/Ø12
    outlet, 80 mm tall, 2 mm wall, EXPORT_PART selector for per-part STLs
    - validation/geometry_check.py: check_reservoir + check_clearance
    (trimesh proximity, 4000-point surface sampling). Min clearance 6.5 mm.
    - renders/v4_2/: iso, cross (X-plane), side, assembly cross-section
    - viewer: loads reservoir.stl translucent, seeds-per-second slider,
    gravity seed-spawn animation, X-plane cross-section, info panel
    with drop distance + min cl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
    [disc.stl, reservoir.stl, v4_2_reservoir.scad]
2026-04-27 Phase 2 fix: pickup θ=110°, release θ=70° per V4 drawing (D5)
    - Pickup and release both sit near disc top, symmetric around Y axis.
    - Outlet now at (-14.365, 27.907, 35.000), 7.1 mm above pickup.
    - Validation regression: outlet +Y rim clips disc by ~0.1 mm. Reported,
    options documented in D5; awaiting Hendrik's call.
    - Build_log notes: a guidance-free released seed misses the central
    hole — Phase 3 deflector is mandatory, not optional.
    [reservoir.stl]
2026-04-27 Phase 2 V5: architecture switch to vacuum-pickup bottom seed-pool (D6)
    - Pickup at θ=270° (disc bottom, in pool); release at θ=90° (top, above
    central hole). Travel arc is 180° along the rim with θ decreasing.
    - v4_2_reservoir.scad → v5_2_seed_pool.scad. New 60×40×20 mm open bowl
    with V-trough bottom; disc-envelope subtraction carves slots in the
    X=±30 side walls so the disc dips through without breaking the floor
    or front/back walls.
    - Viewer rewritten: 80-seed pool fill, per-hole capture (red glow on
    disc), 180° travel, release with tangential ω×R kick, free-fall to
    show miss-the-central-hole behaviour. New vacuum slider + counters.
    - Rotation reversed (Option 1):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
    [disc.stl, reservoir.stl, seed_pool.stl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]
2026-04-27 Phase 3 V5: afstrijker + geleider + drop-tube + visual fixes
    - Afstrijker singulator at θ=250°, 18×2×8 mm tangent blade on disc-front
    face. 5% probability of knocking attached seeds back to the pool
    (singulation visualisation).
    - Geleider catch-chute: lofted hull from 40×20 mm rect mouth (z=20, y=30)
    to Ø30 throat at z=−6 (lowered from spec'd z=5 to clear the disc-body
    slab |z−y|≤2.83). Disc envelope subtracted with 3 mm clearance — slot
    leaks, sealing brushes deferred. See D7.
    - Drop-tube: Ø30 OD / Ø24 ID straight pipe from geleider throat (z=−6)
    down to z=−52, fits Ø50 central hole with 10 mm radial slop.
    - Viewer animation overhaul: pool→attached→falli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
    [afstrijker.stl, afstrijker2.stl, drop_tube.stl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]
2026-04-27 Phase 3 V5 fix: derive FRONT_NORMAL from pool reference
    Previous viewer used DISC_FRONT_VIS = +DISC_NORMAL = (0, -sin45°, +cos45°)
    to place attached seeds on the camera-facing side. That sign was wrong:
    seeds appeared embedded in the disc plane in side view because the offset
    direction was the back-face normal.
    Root-cause fix: use the pool as ground truth. Pool seeds touch the disc
    from the front side by construction, so they define which side is "front".
    disc_plane_eq(x,y,z) = -sin45°·y + cos45°·z. A pool seed at (0,-29.7,-33)
    gives -2.33 < 0 → front side. FRONT_NORMAL is the unit vector pointing
    in the direction of decreasing disc_plane_eq:
    FRONT_NORMAL = (0, +sin45°, -cos45°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
2026-04-27 Phase 4 V5: vacuum chamber + 4 mm pickup holes + corrected seed mechanics
    - PICKUP_HOLE_DIA 2.5 -> 4.0 mm (still < 6 mm soybean, more suction area)
    - Attached-seed offset = SEED_RADIUS (3 mm), not 5 mm: seed-bottom rests
    on disc-front face around the hole
    - New scad/v5_4_vacuum_chamber.scad: hollow annular sector R 30..50,
    depth 8, 180-deg arc through theta=180, Ø12 x 30 mm hose nipple
    - New geometry_check.check_vacuum_chamber: watertight, sector x range,
    back-side centroid - all PASS (392 verts, 780 faces)
    - Viewer: vacuumChamberMat (alpha 0.30), 40 per-hole additive blue glow
    markers visible when world.x <= 0 AND vacuum > 5, vacuum=0 drops every
    attached seed immediately. Two ne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
    [disc.stl, v5_4_vacuum_chamber.scad, vacuum_chamber.stl]
2026-04-27 V5 anchor-based verification: afstrijkers as FRONT_NORMAL ground truth
    Replaces abstract coordinate reasoning with anchor-based positioning.
    Afstrijkers physically must be on the seed-side; they are the visual
    ground truth. Once their positions are derived from FRONT_NORMAL and
    visually confirmed on the pool side, every other front-side component
    uses the same FRONT_NORMAL; the chamber uses -FRONT_NORMAL.
    - viewer.js: logAnchorReport() prints expected centroids for both
    afstrijkers, the pickup-seed, the geleider mouth, and the chamber,
    with same-Y-sign and disc_plane_eq checks. On STL load each mesh
    centroid is compared to the computed anchor.
    - renders/v5_4_anchor/: iso, side_x, fron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
2026-04-27 V5 FLIP: seeds + afstrijkers to camera-visible side, chamber hidden behind
    Hendrik observed in the viewer that the assignment was wrong: pool, attached
    seeds, and afstrijkers should be on the operator-visible disc face, with the
    vacuum chamber + nipple hidden behind. The disc plane already separated the
    two halves correctly; only the side assignment needed flipping.
    - scad/v5_4_vacuum_chamber.scad: added mirror([0,0,1]) before the disc tilt,
    moving the chamber to the back-of-disc face. Centroid now (-26.67, +6.67,
    -6.67); disc_plane_eq=-9.43.
    - scad/v5_3_barriere_geleider.scad: removed mirror([0,0,1]) from both
    afstrijker() and afstrijker2() so the blades follow the seed side.
    Centr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
    [afstrijker.stl, afstrijker2.stl, v5_3_barriere_geleider.scad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]
2026-04-27 V5 polish: vacuum-respecting release glide + front-face tube ports
    - viewer: glideToThroat() 2-stage release path keeps seed on disc
    face (disc-local-Z=+3) until central hole, then drops through.
    No more clipping through the disc plate at theta=90.
    - viewer: darker shell materials (pool/afstrijker/geleider/drop_tube/
    vacuum_chamber) at lower opacity for cleaner contrast.
    - pool: feeder tube (OD16, 60deg) + vac-cleanup tube (OD32, 45deg)
    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
    [seed_pool.stl, v5_2_seed_pool.scad]
2026-04-27 viewer: cache-bust STL loads + log bounds for diagnostics
2026-04-27 v5.5.0: wider feeder + vac tube to top at 80deg
    - Feeder OD 16->18, ID 12->14: bigger bore reduces bridging risk
    for soybean Ø~6.
    - Vac-cleanup tube relocated from front-mount/45deg to top-mount/
    80deg (10deg off vertical), mouth INSIDE the pool 7mm above
    floor at (0, -42, -30). Hose attach side tilts toward operator;
    mouth eq=+8.5 keeps tube body clear of disc body slab.
    - New vac_clean_tube_outer/bore modules; no longer share the
    front-mount helper.
    - Pool STL: 865v/1742f -> 899v/1810f, watertight.
    - Validation x_extent tolerance tightened to +/-1.0.
    [seed_pool.stl, v5_2_seed_pool.scad]
2026-04-27 v5.5.1: V-cone in both X&Y + floor lowered to z=-50 (clears teeth)
    Resolves long-standing disc_above_floor validation fail (teeth at
    z=-47.76 vs old floor at -37). Floor now -50, gap +2.24 mm.
    - SEED_POOL_DEPTH 20→33, SEED_POOL_Z_FLOOR -37→-50
    - SEED_POOL_BOTTOM_X 6→4, SEED_POOL_BOTTOM_Y new=4 (true V-cone)
    - seed_pool_cavity hull bottom uses bottom_y not inner_y
    - validation z_floor expected updated, disc_above_floor PASSES
    - STL: 899v→985v, watertight, bounds z[-50,+55.97]
    Half-circle wraparound bowl deferred to v5.5.2.
    [seed_pool.stl, v5_2_seed_pool.scad]
2026-04-27 v5.5.2: half-disc pool wraps disc bottom 180°
    Body geometry changes from cube(60×40×33) to half-cylinder R=55,
    opening at y=0. Catches seeds detaching mid-travel from any rim
    position whose XY projection lands in the half-disc footprint.
    - SEED_POOL_R_OUTER=55 sized to keep tube anchors inside body
    (feeder √(15²+50²)=52.2 < 55, vac √42²=42 < 55)
    - Cavity hulled from half-disc top (R=53) to V-cone patch (4×4)
    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
    [seed_pool.stl, v5_2_seed_pool.scad]
2026-04-28 v5.6.0: Phase 5 — top-half recovery bowl + clean-cycle animation
    5a — Top-half recovery bowl (scad/v5_5_recovery_bowl.scad). Half-disc
    shell footprint y >= 0, R_OUTER=55, z in [22, 50]. Mirrors the bottom
    pool (D10) on the y >= 0 side. Floor sits flush on the geleider; 40x20
    drain at y=30 aligns with the geleider catch-mouth. Disc-envelope
    subtraction (3 mm clearance) carves the slot where the disc rim crosses
    the bowl outer wall. STL 286v/572f, watertight; all 7 bowl validation
    checks PASS.
    5b — Self-cleaning vacuum cycle (viewer). New "Start clean cycle" button
    forces vacuum to 0 internally, suppresses pool refill, and animates pool
    seeds at 3/s through the top-mount vac-cleanup tub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
    [disc.stl, recovery_bowl.stl, reservoir.stl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]
2026-04-28 v5.6.1: vacuum chamber 1 mm air gap (Hendrik's call)
    Phase-4 chamber sat against the disc with EPS=0.01 mm slop. Real
    disc-vacuum machines run 0.5-1 mm with a PTFE wiper or rubber lip.
    Hendrik chose 1 mm.
    - VAC_CHAMBER_AIR_GAP = 1.0 added to parameters.scad
    - v5_4_vacuum_chamber.scad: chamber-front translate from
    DISC_THICKNESS/2 - EPS to DISC_THICKNESS/2 + VAC_CHAMBER_AIR_GAP
    - STL re-exported, watertight, centroid shifted from (-26.67, +6.67,
    -6.67) to (-26.67, +7.38, -7.38) — exactly 1 mm along the
    back-normal (sin/cos 45°)
    - viewer.js ANCHOR.chamber updated; anchor verification PASS
    - Validation: 36/36 PASS
    [v5_4_vacuum_chamber.scad, vacuum_chamber.stl]
2026-04-28 docs: post-Phase-5 audit report snapshot
    Captured at v5.6.0 / phase5-backup; references resolved by v5.6.1
    (chamber air gap = 1 mm).
2026-04-28 v5.7.0: Phase 6 — integrated disc-mal element
    Major architectural shift per Hendrik's Phase-6 spec. Consolidates the
    Phase-4 vacuum chamber and parts of Phase 5 into one 3D-printable plate
    that holds the disc, drives it, and provides vacuum suction.
    - scad/v5_6_disc_mal.scad — 180x180x15 plate tilted 45° around world-X.
    Disc-recess Ø134 x 5 deep on plate-front. Integrated vacuum chamber
    cavity (R=32..52, 180° sector, 8 deep). ISO-3601 O-ring groove on
    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
    [mal_plate.stl, motor.stl, pinion.stl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]
2026-04-28 v5.8.0: Phase 7 — integrated transparent housing
    Per Hendrik's Phase-7 spec. Replaces archived seed-pool with a funnel-
    shaped hopper, integrates feeder + vac-cleanup tubes as wall-channels
    (short connector stubs only), adds transparent protective lid with
    rubber dust-seal ring at disc-OD radius.
    - scad/v5_7_housing.scad (NEW) — hopper (100x80 wide top → 30x30
    narrow bottom, 80 mm tall + 20 mm pool below), lid (Ø144 x 4mm with
    cutouts for pickup/release/drop-tube), dust ring (NBR-style
    Ø130-144 x 3mm at disc-OD, dark red).
    - scad/v5_2_seed_pool.scad → scad/archive/. seed_pool.stl deleted from
    stl/v5_2/ and viewer/models/.
    - scad/v5_3_*.scad and scad/v5_6_*.scad: removed `u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
    [dust_ring.stl, hopper.stl, lid.stl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]
2026-04-28 v5.8.1: wider/sounder lid + shallower pool
    Browser eyeball feedback on v5.8.0:
    - lid was too slim → widened OD 144→200, thickness 4→6, added 15 mm
    side rim (4 mm thick) so the lid wraps the disc rim
    - pool extended below plate-front-edge → pool depth 20→14, floor
    raised z=-67→-61 (just above plate-front-bottom at z=-61.7)
    - dust-ring OD decoupled from lid OD (new DUST_RING_OD=144)
    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
    [dust_ring.stl, hopper.stl, lid.stl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]
2026-04-28 v5.8.2: lid as annular ring; hopper at pickup zone
    Browser eyeball v5.8.1: lid too large, hopper too far from pickup,
    hopper floating in space.
    - Lid: annular ring OD 140 / inner Ø 112 (covers outer disc body +
    teeth + 4 mm bezel; inner area where pickup holes live stays open).
    Side rim removed. Cutouts at θ=270°/90° now narrow radial slots.
    - Hopper: repositioned to pickup-hole plan (Y_centre -46.67 → -30),
    shrunk significantly (top 100×80→50×35, bottom 30×30→22×22, height
    80→25, pool depth 14→10). Pool surface raised z=-47→-32, floor
    z=-61→-42 (well above plate-front-edge).
    - Vac-cleanup connector temporarily retired (anchor was inside open
    hopper-top cav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
    [dust_ring.stl, hopper.stl, lid.stl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]
2026-04-28 v5.8.3: closed lid ring + 100 seeds filling full hopper volume
    Browser eyeball v5.8.2:
    - "seed should stay in the hopper, not at the bottom"
    - "bottom and upper cover ring closed"
    - "no bottomhole in hopper"
    - "let 100 seeds enter, after 80 seeds 20 sucked out"
    Changes:
    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
    [lid.stl, v5_7_housing.scad]
2026-04-28 v5.8.4: vac-cleanup tube re-added + feeder seed-flow animation
    Browser eyeball v5.8.3: "cleanout!", "vacuum tube as large as feeder",
    "feeder should show seeds flowing into hopper, not hanging in the air".
    - Vac-cleanup tube as a standalone STL (NOT booleaned with hopper).
    OD 18 / ID 14 matching feeder. Mouth at world (0, -35, -34); tube
    extends 60 mm at 80° elev tilting toward operator. Watertight
    256v/512f.
    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
    [v5_7_housing.scad, vac_tube.stl]
2026-04-28 v5.8.5: round mal-plate + lid retention clips
    Browser eyeball v5.8.4: "make it a nice 1cm rounding around the disc,
    with clips to fix the upper cover. Round seed element, not a tile."
    - Plate body: 180×180 square → Ø152 round (disc OD 132 + 2×10 mm
    margin). MAL_PLATE_OD param added; X/Y kept for validation
    back-compat.
    - 4 lid retention posts on plate-front at disc-local θ ∈ {45°, 135°,
    225°, 315°}, R=72 (just outside lid OD/2=70). Each: OD 10 × 14 mm
    tall, M3 clearance bore. Clip top at z=+16.5, reaches past lid
    front (z=+10) for clamping.
    Plate STL: 705v/1410f → 1851v/3702f. Centroid still on back side
    (eq=-6.79). Validation 47/47 PASS (x_extent tolerance widened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
    [mal_plate.stl, v5_6_disc_mal.scad]
2026-09-05 v7 proposal: closed drum, ring gear behind seal land, collar for last-seed pickup, count mode; SCAD + STLs (unbuilt)
    [blow_nipple.stl, board_tray.stl, collar.stl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]
